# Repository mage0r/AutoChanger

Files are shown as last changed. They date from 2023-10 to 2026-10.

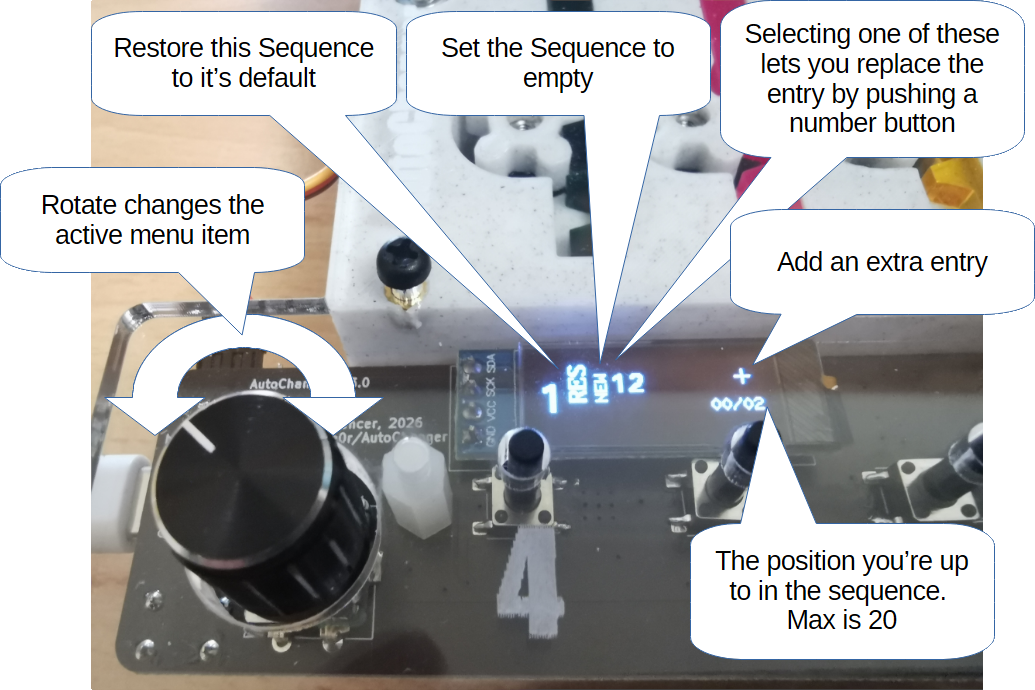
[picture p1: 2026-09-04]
images/Version3.9-howto-4.png

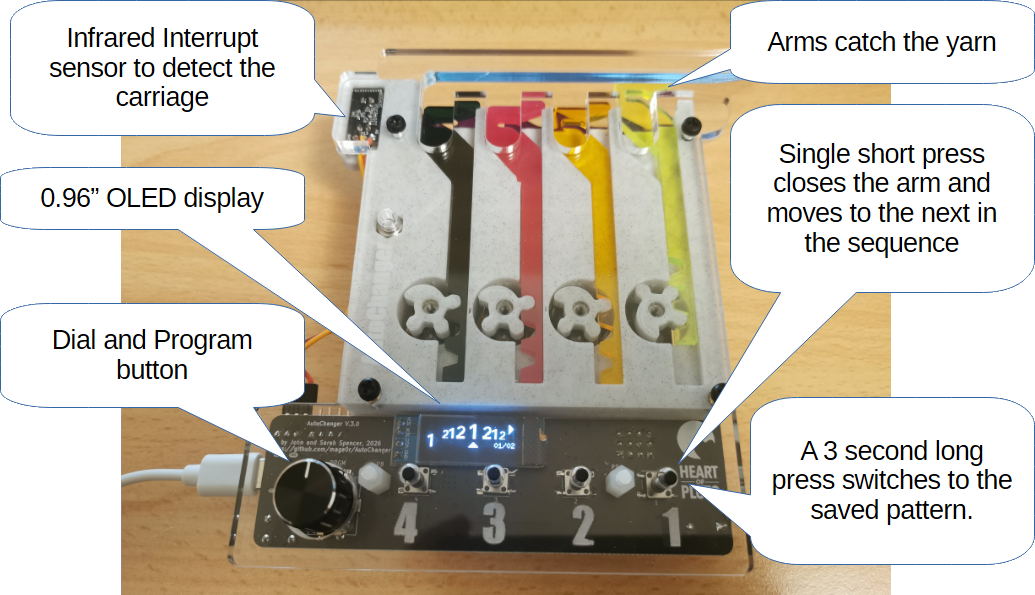
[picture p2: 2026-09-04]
images/Version3.9-howto-1.png

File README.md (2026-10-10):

AutoChanger - A Knitting Machine Auto Colour Changer to replace a Brother KRC-900
=============

This project was designed to provide a lower cost replacement for the commercial auto colour changer available from Brother for their 1980's electronic knitting machines.

How to use your AutoChanger
============

Thanks for purchasing or building your own AutoChanger.  I've put together a page of all the different features for you to try.

It is highly recommended you upgrade your AutoChanger firmware to the latest.  The current latest is v4.2.9

[How to Upgrade Your AutoChanger Firmware](https://github.com/mage0r/AutoChanger/wiki/How%E2%80%90to%E2%80%90upgrade)

[How to Use Your AutoChanger](https://github.com/mage0r/AutoChanger/wiki/How-to-use-Firmware-Version-4.2)

[Still using Version-3.9?  Check it out here](https://github.com/mage0r/AutoChanger/wiki/How-to-use-Firmware-Version-3.9)

Where did this come from?
============

You can read about the progress of this design at the following links:

[Building a better colour changer - Part 1 - Designing Hardware](https://github.com/mage0r/AutoChanger/wiki/Building-a-better-Colour-Changer-%E2%80%93-Part-1-%E2%80%93-Designing-hardware)

[Building a better colour changer - Part 2 - Firing the lasers](https://github.com/mage0r/AutoChanger/wiki/Building-a-better-Colour-Changer-%E2%80%93-Part-2-%E2%80%93-Firing-the-Lasers)

[Building a Better Colour Changer – Interlude – The KRC-1000E](https://github.com/mage0r/AutoChanger/wiki/Building-a-Better-Colour-Changer-%E2%80%93-Interlude-%E2%80%93-The-KRC%E2%80%901000E)

[Building a Better Colour Changer – Part 3 – Revising the design](https://github.com/mage0r/AutoChanger/wiki/Building-a-Better-Colour-Changer-%E2%80%93-Part-3-%E2%80%93-Revising-the-design)

For the sake of completeness, the early versions of this project are described at [Hardware Version 1.0 to 2.0]https://github.com/mage0r/AutoChanger/wiki/Hardware-Version-1.0-to-2.0)

Version 2.0 to 3.0 was TinyPico Based.  You can read about it at [Hardware Version 2.0 to 3.0](https://github.com/mage0r/AutoChanger/wiki/Hardware-Version-2.0-to-3.0)

Version 3.0 is a whole new build using an ESP32s3.  You can read about it at [Hardware Version 3.0](https://github.com/mage0r/AutoChanger/wiki/Hardware-Version-3.0)

CREDITS
------------

This project was designed in 2017 by John and Sarah Spencer
 - [John Spencer](https://github.com/mage0r)
 - [Sarah Spencer](https://github.com/chixor)

Check us out at [Heart Of Pluto](http://heartofpluto.co)

Made at hackmelbourne.org!

SPECIAL THANKS
------------

To the HackMelbourne (CCHS, http://hackmelbourne.org) community of Melbourne, Australia.

To all other open-source developers whose countless hours supported every other aspect of this design.

DISTRIBUTION
------------
The specific terms of distribution of this project are governed by the
license referenced below. Please contact the copyright owner if you wish to modify the board for distribution. Please utilize this design for personal or research projects. Please acknowledge all contributors.

LICENSE
-------
Licensed under the TAPR Open Hardware License (www.tapr.org/OHL).
The "license" sub-folder also contains a copy of this license in plain text format.

Copyright John Spencer, Sarah Spencer, 2017

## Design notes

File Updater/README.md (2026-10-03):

# AutoChanger Deployment Tool

A simple GUI tool for updating an AutoChanger unit's firmware over USB,
without touching anything saved on the device (patterns, config, etc).

This was largely written by Claude Sonnet 5.

## Why this is safe

This tool writes **only** to the two app slots, `app0` (flash offset `0x10000`) and
`app1` (`0x150000`) — the same regions a normal Arduino IDE upload or an OTA update
writes to. It never touches:

- the bootloader
- the partition table
- the OTA boot-selector (`otadata`)
- the SPIFFS filesystem (patterns, config, web files)

**Both slots get the same image, on purpose.** On a unit that has never used OTA
the bootloader always runs `app0`. Once OTA has been used, `otadata` may point at
`app1` instead, and the tool doesn't read `otadata` to find out which is active.
Writing both means the unit boots the new firmware either way. The trade-off: on
an OTA-enabled unit the inactive slot normally holds the *previous* firmware as a
fallback, and this overwrites it — so there's no falling back to the old version
after an update.

This is correct for any unit on the **"Default 4MB with spiffs (1.2MB APP/1.5MB
SPIFFS)"** partition scheme — which includes any v3.9 unit, since those were never
re-partitioned. The tool does **not** currently read the unit's partition table to
confirm that: it only refuses a firmware file that's too large for a slot. If a
unit's scheme is ever changed (e.g. to use more of a 16MB chip's flash), the fixed
offsets and size in `deploy_tool.py` (`APP0_OFFSET`, `APP1_OFFSET`,
`APP0_MAX_SIZE`) would be wrong for it, and the tool would write to the wrong
place without complaint.

## Using it

1. Get the firmware `.bin`: in Arduino IDE, **Sketch > Export Compiled
   Binary**. This drops a `.bin` file next to your sketch.
2. Open the AutoChanger Deployment Tool.
3. Browse to that `.bin` file.
4. Plug the AutoChanger in over USB, click Refresh if needed, and select its
   port.
5. Click **Update Device**.

The tool checks the firmware isn't larger than the app partition can hold
before doing anything, and shows esptool's live output in the Details pane
so you can see exactly what's happening.

## First-time flash (brand new / blank device)

A chip that's never been flashed has no bootloader or partition table, so a
normal update - which only writes the app itself - produces nothing bootable.
Tick "This is a first-time flash on a brand new/blank device" under section 1
and the tool also writes:

| File | Offset | Purpose |
|---|---|---|
| bootloader.bin | `0x0` | second-stage bootloader (ESP32-S3-specific address) |
| partitions.bin | `0x8000` | the partition table itself |
| *(built into the tool)* | `0xe000` | `boot_app0.bin` - selects the first boot slot |
| firmware.bin | `0x10000` / `0x150000` | same as a normal update |

`boot_app0.bin` isn't sketch-specific - it's one fixed file from the ESP32 core
install, embedded directly in the tool rather than something you need to find.

`bootloader.bin` and `partitions.bin` **are** sketch-specific. Arduino's Export
Compiled Binary produces them next to your `.bin`, named `<sketch>.ino.bootloader.bin`
and `<sketch>.ino.partitions.bin` - the tool looks for them there automatically
and fills the fields in if found, or Browse to them otherwise.

Only use this on a device that's genuinely never been flashed. On a device that's
already running AutoChanger it's unnecessary - a normal update is all that's
needed - though since the bootloader/partition table/app all sit before SPIFFS
on the flash, it wouldn't touch your patterns or config even if run by mistake,
as long as the partition scheme itself doesn't change.

## Clearing files after an update (optional)

Ticking files under "3. Clear files on update" makes the tool, once the unit has
restarted on the new firmware, delete them over serial (`RM`) and then run `FIX`
so the unit recreates fresh defaults. The firmware only writes its default web
pages at startup when `config.ini` is missing, so `FIX` is what actually brings
the pages back straight away.

- **HTML & SVG** (ticked by default) and **Patterns** are recreated immediately.
- **Config** is removed *last*, after `FIX`. `FIX` rebuilds `config.ini` from what
  the unit currently has in memory, so removing it first would just write your
  old settings back. It resets to defaults the next time the unit restarts.
- This needs firmware with the serial command feature (`RM`/`FIX`, v4.1+). On
  anything older the tool logs "no response" for each step and carries on.

## Update logs

After every update attempt - successful or not - the tool saves the contents of
the Details pane to a timestamped file such as
`AutoChanger-deploy-2026-09-28_14-30-05.log`, and shows the path when it
finishes. It's written next to the tool (falling back to your home folder, then
the temp folder, if that location isn't writable). Each log starts with a
header - result, port, firmware file with its size and SHA-256, which files were
cleared, and OS/Python/esptool versions - followed by every line of output with a time. Handy to attach when
something goes wrong. Each log only contains what happened since the previous
one, so logs from several updates in one session don't repeat each other.

## Building the executable yourself

PyInstaller can't cross-compile — a Windows `.exe` has to be built on
Windows, a Mac app on a Mac. This folder includes:

- `deploy_tool.py` — the actual tool (pure Python, runs anywhere Python 3 +
  the two requirements are installed, no build needed for that).
- `requirements.txt` — `esptool` and `pyserial`.
- `build_windows.bat` — run on a Windows machine to produce
  `dist\AutoChangerDeployTool.exe`.
- `build_unix.sh` — run on Mac or Linux to produce
  `dist/AutoChangerDeployTool` (Mac users get an unsigned binary; first
  launch may need a right-click > Open to bypass Gatekeeper once).

A Linux build was already produced and tested as part of building this tool
(the build completed cleanly with all dependencies resolving, and the
resulting binary launches and initializes without error) — running the
matching script on Windows and Mac will produce the equivalents for those
platforms.

## Known limitation

Right now this only performs the **safe, app-only update**. It does not yet
support the (destructive) full repartition-and-reflash path for moving a
unit onto a larger partition scheme to use more of a 16MB chip's flash —
that needs a SPIFFS backup/restore step built in before it's safe to offer,
and is intentionally left out of this first version.

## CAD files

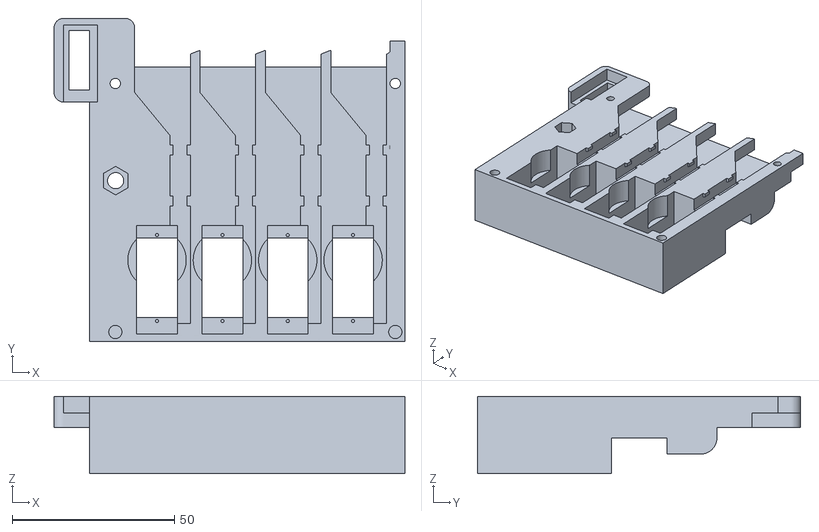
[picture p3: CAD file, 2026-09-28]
Hardware/changer.v.3.0.frame.stl
108.2 x 99.7 x 23.8

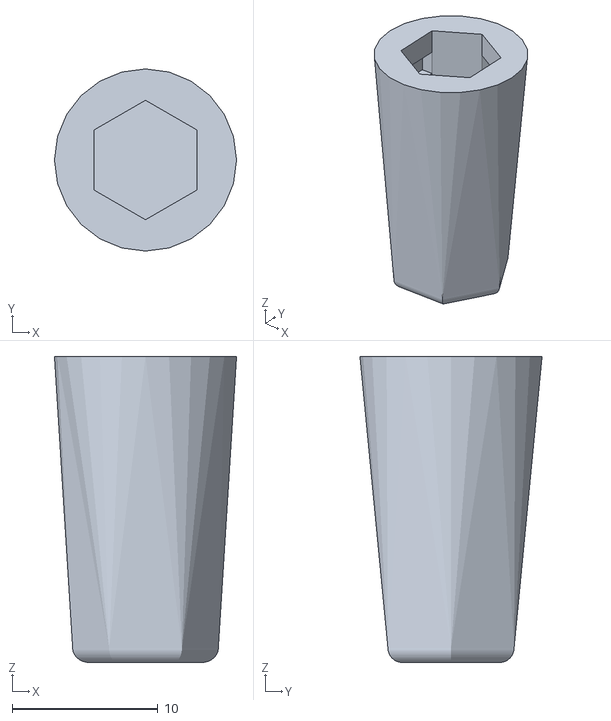
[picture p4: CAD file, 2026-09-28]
Hardware/changer.v.3.0.nut.stl
12.5 x 12.5 x 21.0

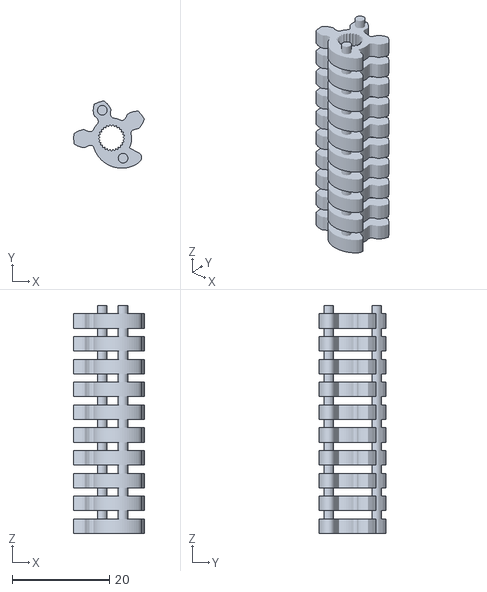
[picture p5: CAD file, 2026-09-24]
Hardware/changer.v.3.0.gearx10.stl
14.6 x 13.9 x 47.0

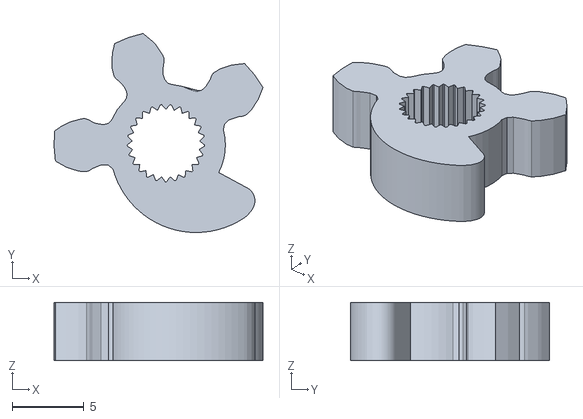
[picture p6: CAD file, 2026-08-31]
Hardware/changer.v.3.0.gear.stl
14.6 x 13.9 x 4.05

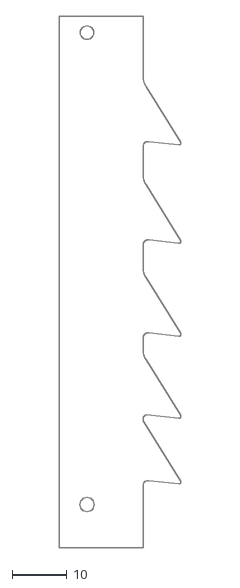
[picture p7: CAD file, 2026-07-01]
Hardware/changer.v.3.0.comb.dxf
22.2 x 97.2

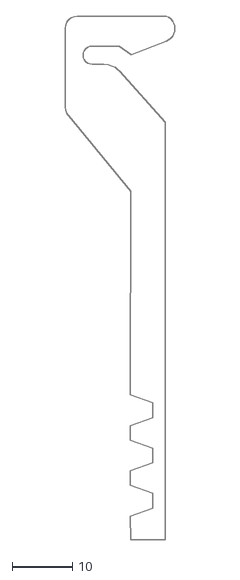
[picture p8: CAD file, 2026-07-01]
Hardware/changer.v.3.0.arm.dxf
18.2 x 87.1

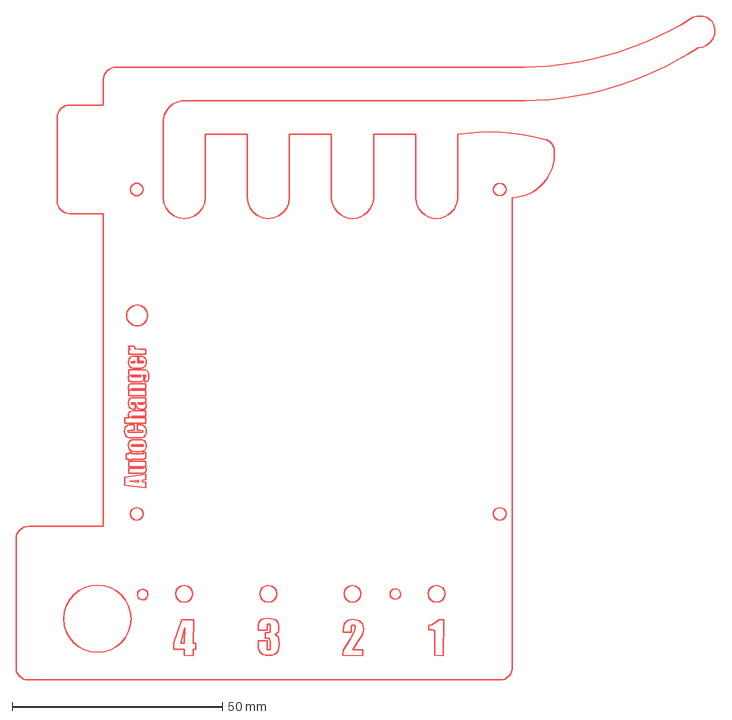
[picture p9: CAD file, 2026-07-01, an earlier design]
Hardware/changer.v.2.5.top.dxf
166.4 x 157.9 mm

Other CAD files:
Hardware/changer.v.3.0.top.dxf
Hardware/changer.v.3.0.skp

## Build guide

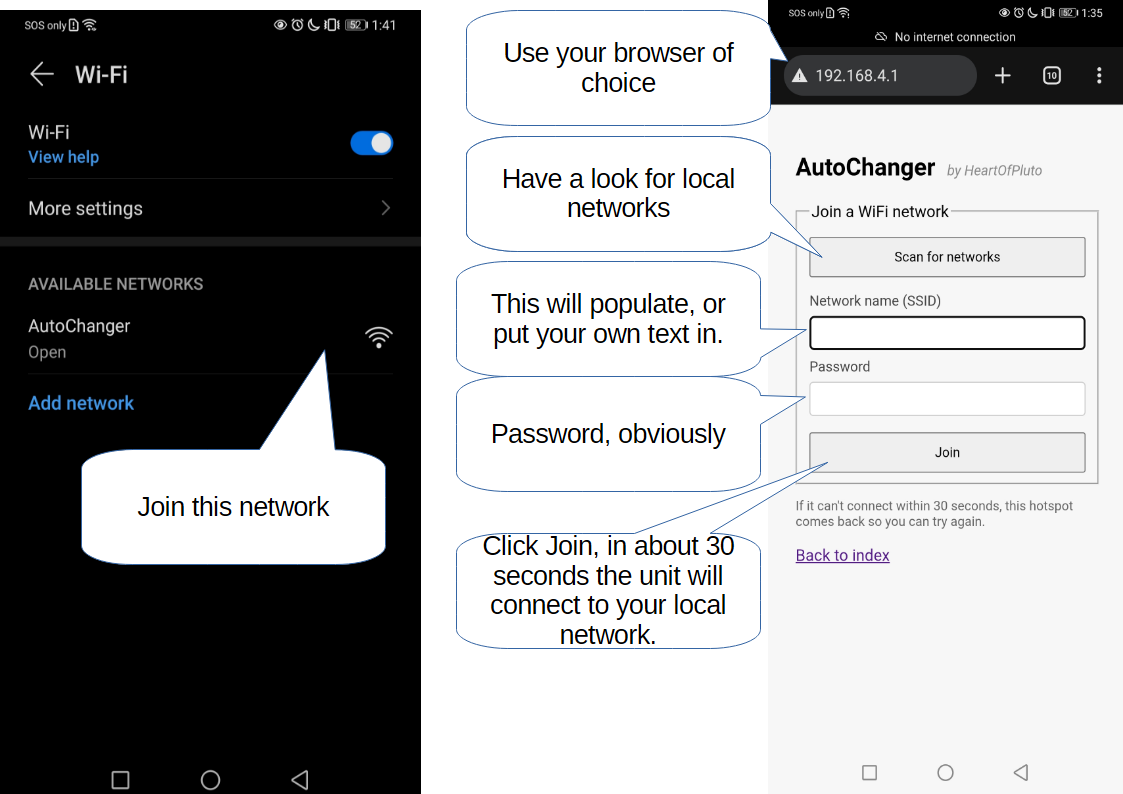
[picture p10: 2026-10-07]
images/Version4.2-howto-7.png

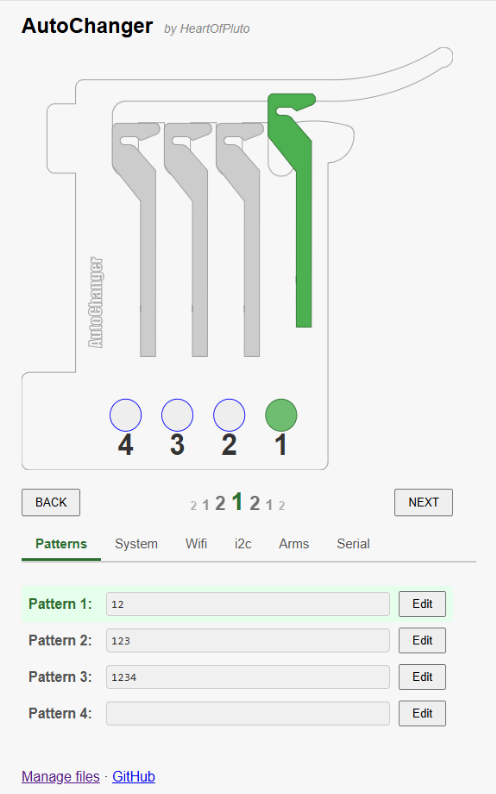
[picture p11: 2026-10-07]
images/Version4.2-howto-8.png

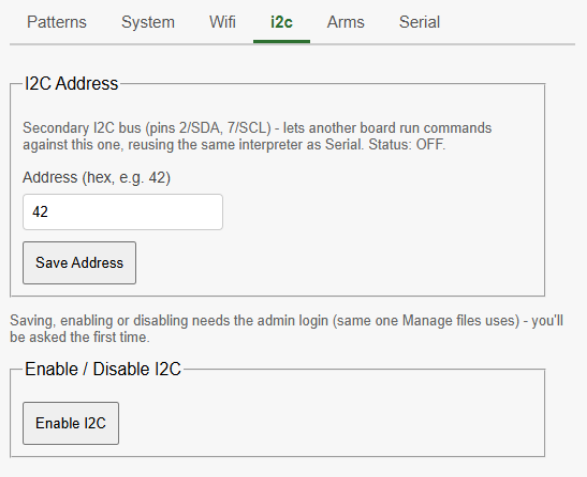
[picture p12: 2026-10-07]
images/Version4.2-howto-11.png

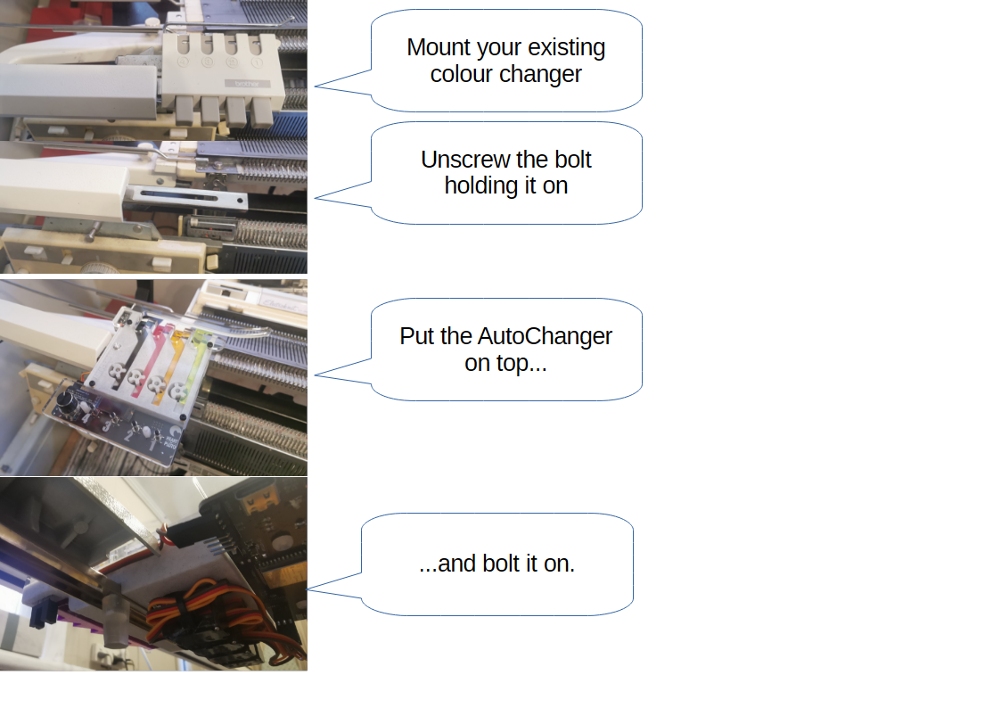
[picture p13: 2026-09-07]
images/Version3.9-howto-5.png

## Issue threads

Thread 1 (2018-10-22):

STEP/dwg files

wifasoi, 2018-10-22:
Hi,
I know i can install sketchup and export from there the necessary files, but i'm a linux user and installing sketchup and use it with wine is a pain (I tried and doesn't work, unfortunately). -*github whiny/entitled user mode engaged*- Can you export the project in for an export of the files in a STEP format (preferred, otherwise stl is workable too), or in this case DWG/dxf/svg would be fine too (but i think there is more work involved). If you don't want to track those files, you can put in a github release (so you don't have to worry about out of sync files).

This is because I want to create a version that work with the ayab board (shhh, is a secret... the ayab peaple dosn't know about it... yet :P) and use a sx1508/9 (I2C IO expander with pwm).

You can close this issue if you don't have time to do it or you think I was too rude... I don't mind.
Thank you for your consideration.

wifasoi, 2018-10-22:
-*event more entiteld github user mode engaged*-
the license requires it   https://github.com/mage0r/AutoChanger/blob/9e84eed463dcbbb184bd24fda50bc8b92860e9d6/Hardware/TAPR_Open_Hardware_License_v1.0.txt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

mage0r, 2018-10-22:
Ah, also, there is a serial/software i2c 4 pin port broken out on the circuit board design that was always intended to provide an uplink to a controller.

You are of course clear to solve the problem any way you like, but having an independent controller provides a few extra advantages.   For example, the user can move threads or change order in the event of a failure.

I've been tempted to do some work with the AYAB project a few times but have been a bit time limited and focused on approaches that are controller agnostic.

wifasoi, 2018-10-23:
I choose the Semtex because you can read key and command LEDs.. but unfortunately I can control servo (learned the hard way)... (I'll use a combination of mpc23017 and some low cost io expander).
And leave the ayab controller do the dirty work... So I don't have to program another micro.
Another reason is to minimize the cost of (ipotetical) product (don't want to transform in a real product, I like to challenge myself :D).

And for the sake of argument:
In theory you can change license whenever you want.. so the rule do not apply to the copyright holder. You are right (if you are the only copyright holder)

And for the sake of argument, again,
maibe DWG is not the best example, but the other are so main stream that are considered "exchange format" between cad programs (STL is the JPEG of the 3d models... I despise them as a exchange format). In the license there are example of "Gerber" and "pdf", once proprietary now so whidespread that are considered "exchange format".

And for last: you can make a GitHub release anytime you want(don't think you need to tag your repo), and you can add out-of-tree files (they are not added to the repo), so it's perfect for adding binary files specific to a commit (or in this case, cad export).

And thanks for your consideration.

wifasoi, 2018-10-23:
Wow, that was log...
TL;DR: you're right. I meant any cad exchange file. GitHub release are perfect to add out-of-tree files. And thanks for your time.

mage0r, 2018-10-23:
https://github.com/mage0r/AutoChanger/releases/tag/1.6

Closed 2018-10-23.

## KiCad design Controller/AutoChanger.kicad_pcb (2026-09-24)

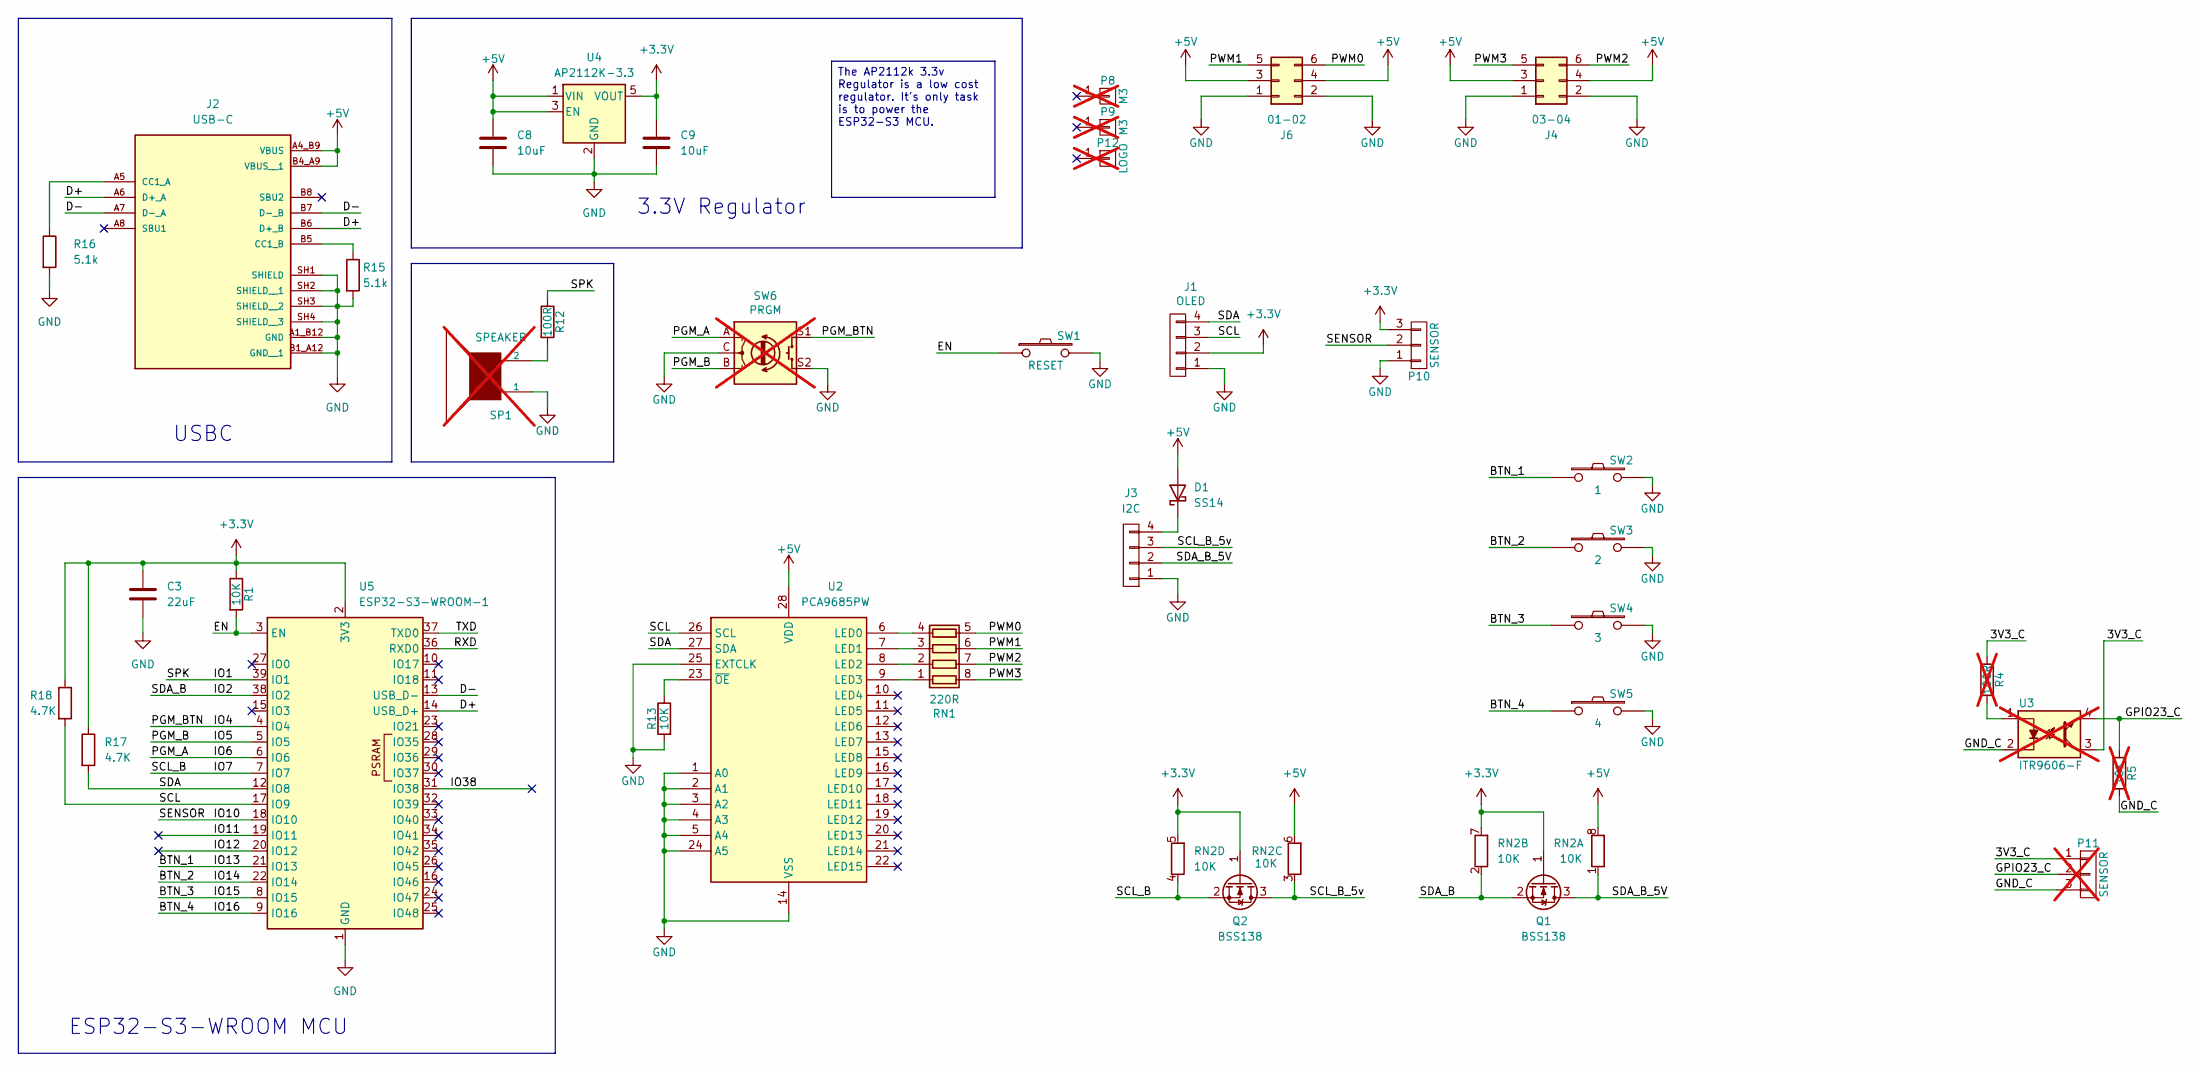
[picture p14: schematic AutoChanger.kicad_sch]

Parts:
C3: 22uF; C_0603_1608Metric; LCSC C59461
C8, C9: 10uF; C_0603_1608Metric; LCSC C19702
D1: SS14; D_SMA; LCSC C2480
J1: OLED; 0.91 OLED; LCSC C5248081
J2: USB-C; AMPHENOL_12402012E212A; PARTREV 4; LCSC C5150972
J3: I2C; CONN-SMD_PH2.0MM-4P-WT; LCSC C53055420
J4: 03-04; HDR-SMD_6P-P2.54-V-M-R2-C3-LS7.5-2; LCSC C3294461
J6: 01-02; HDR-SMD_6P-P2.54-V-M-R2-C3-LS7.5-2; LCSC C3294461
P8, P9: M3; MountingHole_3.2mm_M3; not fitted
P10: SENSOR; CONN-SMD_PH2.0MM-3P-WT; LCSC C53055419
P11: SENSOR; PinHeader_1x03_P2.54mm_Vertical; not fitted
P12: LOGO; logo; not fitted
Q1, Q2: BSS138; SOT-23; LCSC C8490
R1, R13: 10K; R_0603_1608Metric_Pad0.98x0.95mm_HandSolder; LCSC C25804
R4: 100R; R_0603_1608Metric_Pad0.98x0.95mm_HandSolder; LCSC C22775; not fitted
R5: 10K; R_0603_1608Metric_Pad0.98x0.95mm_HandSolder; LCSC C25804; not fitted
R12: 100R; R_0603_1608Metric_Pad0.98x0.95mm_HandSolder; LCSC C22775
R15, R16: 5.1k; R_0603_1608Metric_Pad0.98x0.95mm_HandSolder; LCSC C23186
R17, R18: 4.7K; R_0603_1608Metric_Pad0.98x0.95mm_HandSolder; LCSC C23162
RN1: 220R; R_Array_Concave_4x0603; LCSC C29719
RN2: 10K; R_Array_Convex_4x0603; LCSC C29718
SP1: SPEAKER; Buzzer_12x9.5RM7.6; not fitted
SW1: RESET; SW_SPST_PTS645Sx43SMTR92; LCSC C557614
SW2: 1; SW_SPST_PTS645Sx43SMTR92; LCSC C53202676
SW3: 2; SW_SPST_PTS645Sx43SMTR92; LCSC C53202676
SW4: 3; SW_SPST_PTS645Sx43SMTR92; LCSC C53202676
SW5: 4; SW_SPST_PTS645Sx43SMTR92; LCSC C53202676
SW6: PRGM; RotaryEncoder_Alps_EC12E-Switch_Vertical_H20mm; LCSC C470742; not fitted
U2: PCA9685PW; TSSOP-28_4.4x9.7mm_P0.65mm; LCSC C2678753
U3: ITR9606-F; ITR9606; not fitted
U4: AP2112K-3.3; SOT-23-5; LCSC C51118
U5: ESP32-S3-WROOM-1; LCSC C2913202

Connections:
+3.3V: C3.1, C9.1, J1.2, P10.3, Q1.1 (G), Q2.1 (G), R1.1, R17.1, R18.1, RN2.5 (R4.2), RN2.7 (R2.2), U4.5 (VOUT), U5.2 (3V3)
+5V: C8.1, D1.2 (A), J2.A4_B9 (VBUS), J2.B4_A9 (VBUS__1), J4.3, J4.4, J6.3, J6.4, RN2.6 (R3.2), RN2.8 (R1.2), U2.28 (VDD), U4.1 (VIN), U4.3 (EN)
/3V3_C: P11.1, R4.1, U3.3
/BTN_1: SW2.1, U5.21 (IO13)
/BTN_2: SW3.1, U5.22 (IO14)
/BTN_3: SW4.1, U5.8 (IO15)
/BTN_4: SW5.1, U5.9 (IO16)
/D+: J2.A6 (D+_A), J2.B6 (D+_B), U5.14 (USB_D+)
/D-: J2.A7 (D-_A), J2.B7 (D-_B), U5.13 (USB_D-)
/EN: R1.2, SW1.1, U5.3 (EN)
/GND_C: P11.3, R5.2, U3.2
/GPIO23_C: P11.2, R5.1, U3.4
/IO1: R12.1, U5.39 (IO1)
/IO2: Q1.2 (S), RN2.2 (R2.1), U5.38 (IO2)
/IO4: SW6.S1, U5.4 (IO4)
/IO5: SW6.B, U5.5 (IO5)
/IO6: SW6.A, U5.6 (IO6)
/IO7: Q2.2 (S), RN2.4 (R4.1), U5.7 (IO7)
/IO10: P10.2, U5.18 (IO10)
/IO11: U5.19 (IO11)
/IO12: U5.20 (IO12)
/IO38: U5.31 (IO38)
/PWM0: J6.6, RN1.5 (R4.2)
/PWM1: J6.5, RN1.6 (R3.2)
/PWM2: J4.6, RN1.7 (R2.2)
/PWM3: J4.5, RN1.8 (R1.2)
/RXD: U5.36 (RXD0)
/SCL: J1.3, R18.2, U2.26 (SCL), U5.17 (IO9)
/SCL_B_5v: J3.3, Q2.3 (D), RN2.3 (R3.1)
/SDA: J1.4, R17.2, U2.27 (SDA), U5.12 (IO8)
/SDA_B_5V: J3.2, Q1.3 (D), RN2.1 (R1.1)
/TXD: U5.37 (TXD0)
GND: C3.2, C8.2, C9.2, J1.1, J2.A1_B12 (GND), J2.B1_A12 (GND__1), J2.SH1 (SHIELD), J2.SH2 (SHIELD__1), J2.SH3 (SHIELD__2), J2.SH4 (SHIELD__3), J3.1, J4.1, J4.2, J6.1, J6.2, P10.1, R13.2, R15.2, R16.2, SP1.1, SW1.2, SW2.2, SW3.2, SW4.2, SW5.2, SW6.C, SW6.S2, U2.1 (A0), U2.2 (A1), U2.3 (A2), U2.4 (A3), U2.5 (A4), U2.14 (VSS), U2.24 (A5), U2.25 (EXTCLK), U4.2 (GND), U5.1 (GND), U5.40 (GND), U5.41 (GND)
unnamed: D1.1 (K), J3.4
unnamed: J2.A5 (CC1_A), R16.1
unnamed: J2.B5 (CC1_B), R15.1
unnamed: R4.2, U3.1
unnamed: R12.2, SP1.2
unnamed: RN1.1 (R1.1), U2.9 (LED3)
unnamed: RN1.2 (R2.1), U2.8 (LED2)
unnamed: RN1.3 (R3.1), U2.7 (LED1)
unnamed: RN1.4 (R4.1), U2.6 (LED0)
unnamed: R13.1, U2.23 (~OE)

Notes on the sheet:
USBC
ESP32-S3-WROOM MCU
3.3V Regulator
The AP2112k 3.3v Regulator is a low cost regulator. It's only task is to power the ESP32-S3 MCU.

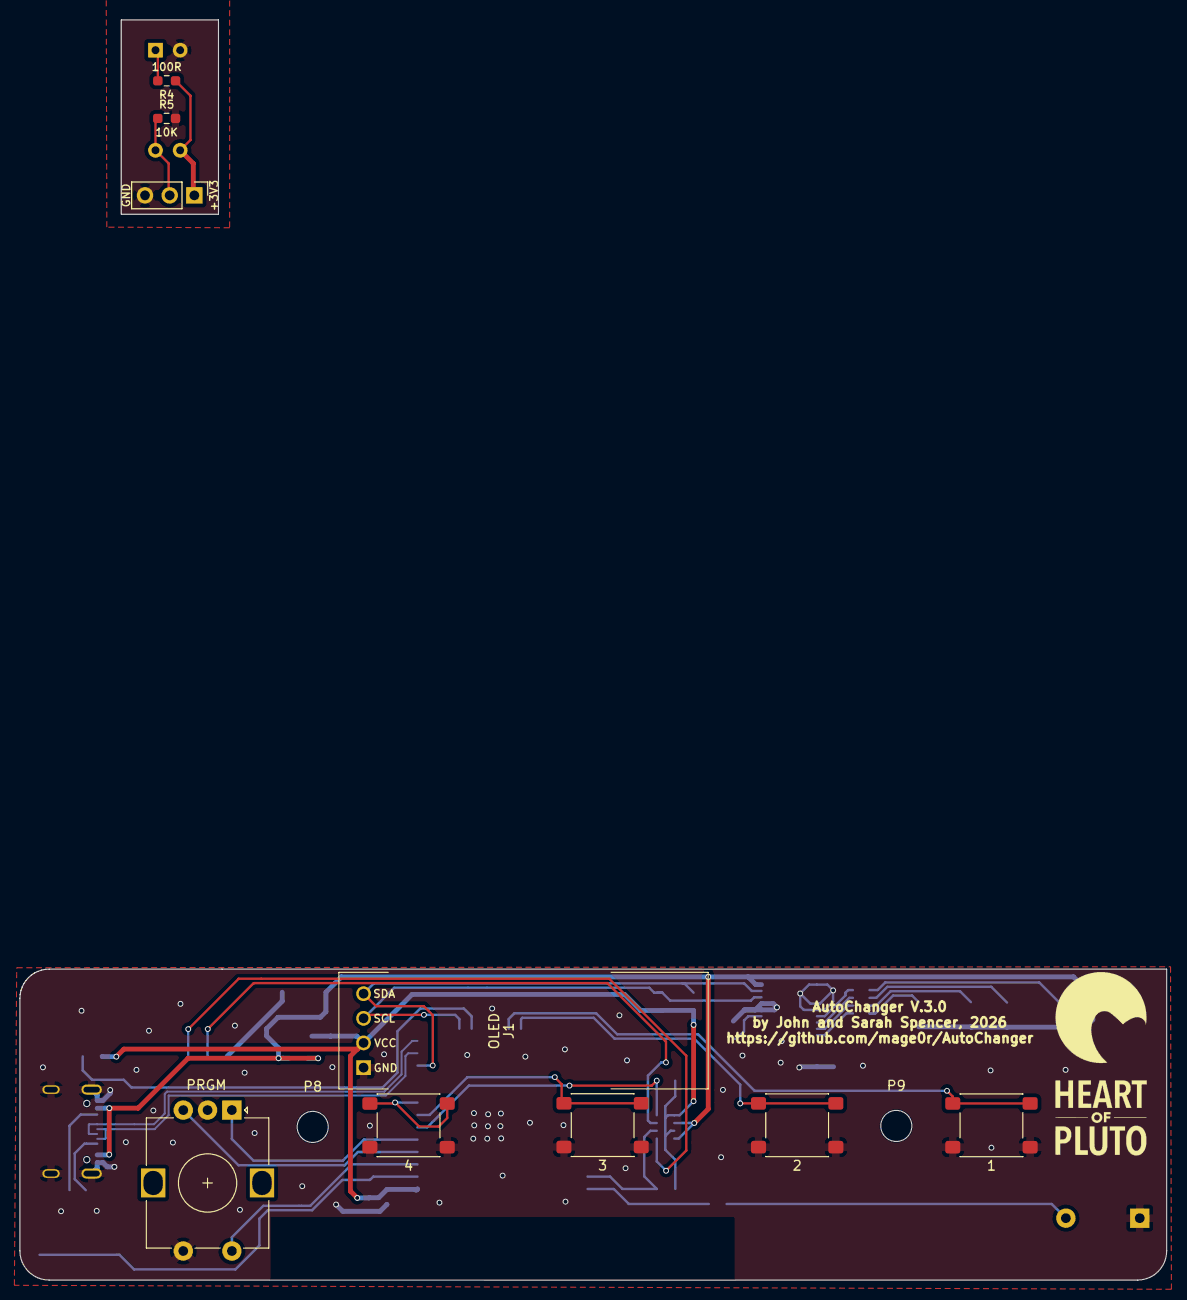
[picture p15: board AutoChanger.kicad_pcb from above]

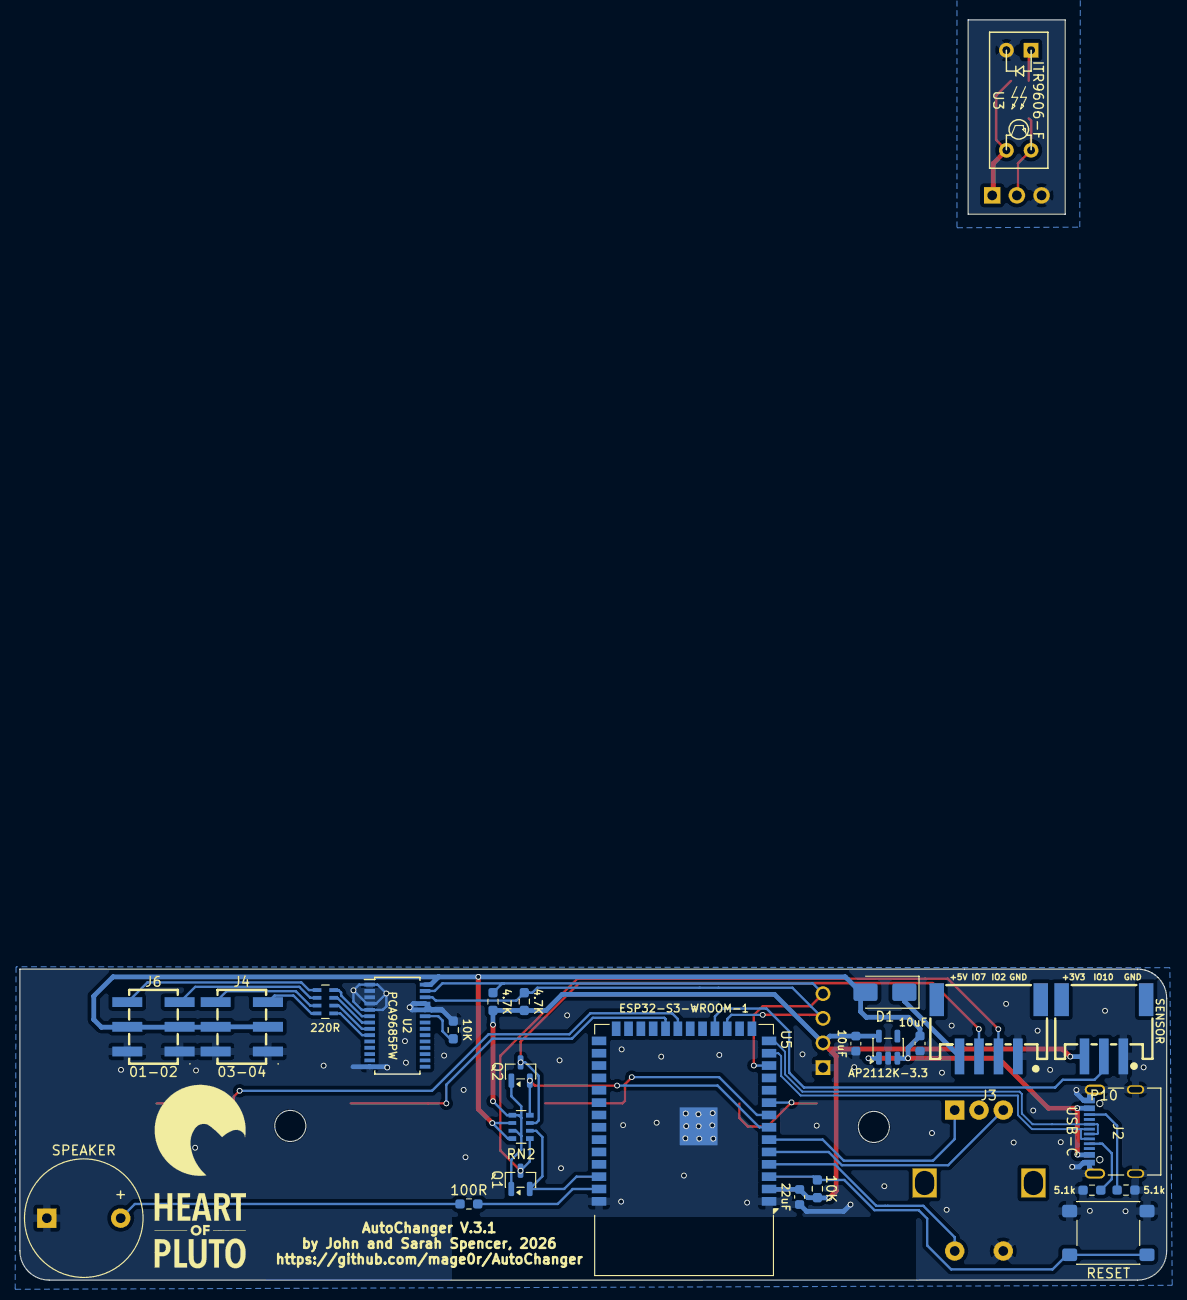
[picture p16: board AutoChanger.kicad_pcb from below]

Board: 2 copper layers, 118.0 x 32.0 mm, 39 parts (27 on the bottom side), 38 nets.

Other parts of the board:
P12#2: LOGO; logo

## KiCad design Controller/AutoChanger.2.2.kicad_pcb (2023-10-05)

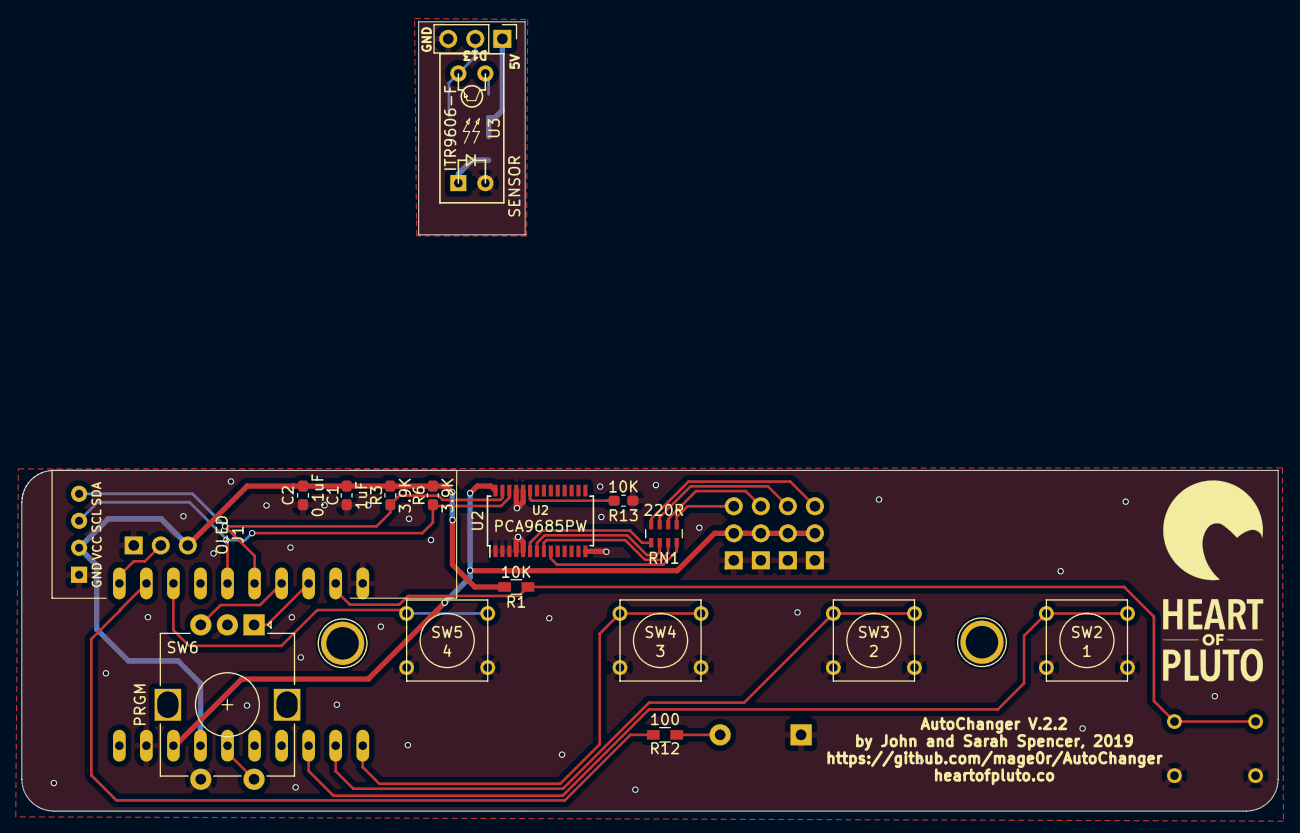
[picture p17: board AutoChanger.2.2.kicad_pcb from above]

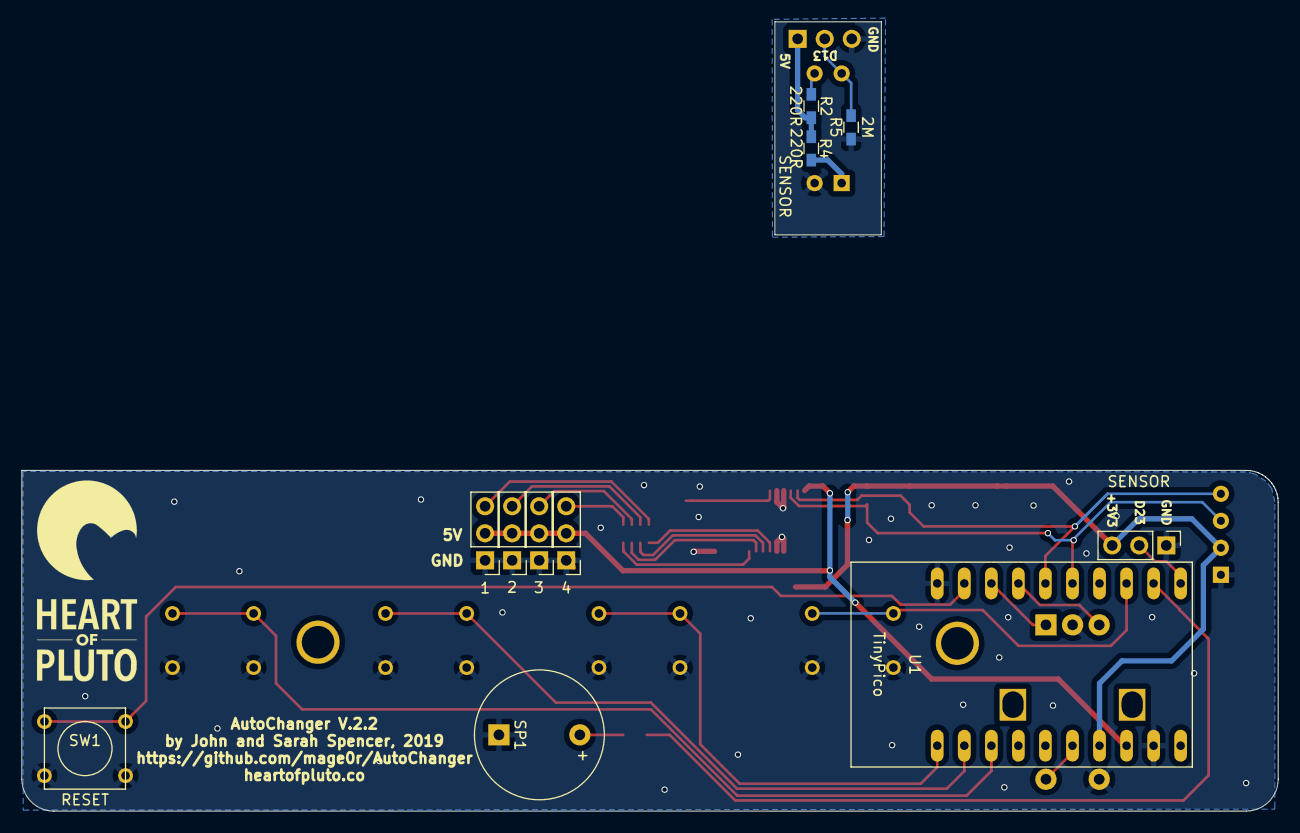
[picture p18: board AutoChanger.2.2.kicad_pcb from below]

Board: 2 copper layers, 118.0 x 32.0 mm, 32 parts (12 on the bottom side), 30 nets.

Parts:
C1: 1uF; C_0603_1608Metric_Pad1.05x0.95mm_HandSolder
C2: 0.1uF; C_0603_1608Metric_Pad1.05x0.95mm_HandSolder
J1: OLED; 0.91 OLED
P3: 1; Pin_Header_Straight_1x03_Pitch2.54mm
P4: 2; Pin_Header_Straight_1x03_Pitch2.54mm
P5: 3; Pin_Header_Straight_1x03_Pitch2.54mm
P6: 4; Pin_Header_Straight_1x03_Pitch2.54mm
P8, P9: M3; 1pin
P10, P11: SENSOR; Pin_Header_Straight_1x03_Pitch2.54mm
P12, P12#2: LOGO; logo
R1: 10K; R_0603_HandSoldering
R2, R4: 220R; R_0603_HandSoldering
R3, R6: 3.9K; R_0603_1608Metric_Pad1.05x0.95mm_HandSolder
R5: 2M; R_0603_HandSoldering
R12: 100; R_0603_HandSoldering
R13: 10K; R_0603_1608Metric_Pad1.05x0.95mm_HandSolder
RN1: 220R; R_Array_Concave_4x0603
SP1: SPEAKER; Buzzer_12x9.5RM7.6
SW1: RESET; SW_PUSH_SMALL
SW2: 1; SW_PUSH_SMALL
SW3: 2; SW_PUSH_SMALL
SW4: 3; SW_PUSH_SMALL
SW5: 4; SW_PUSH_SMALL
SW6: PRGM; RotaryEncoder_Alps_EC12E-Switch_Vertical_H20mm
U1: TinyPico
U2: PCA9685PW; TSSOP-28_4.4x9.7mm_P0.65mm
U3: ITR9606-F; ITR9606

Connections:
+3V3: C1.1, C2.1, J1.2, P10.3, R1.1, R3.1, R6.1, U1.7
+5V: P3.2, P4.2, P5.2, P6.2, U1.8, U2.28
/3V3_C: P11.1, R2.1, R4.1
/GND_C: P11.3, R5.2, U3.2
/GPIO4: SW6.S1, U1.6
/GPIO18: SW5.1, U1.13
/GPIO19: R12.1, U1.12
/GPIO23: P10.2, U1.11
/GPIO25: SW4.1, U1.1
/GPIO25_C: P11.2, R5.1, U3.4
/GPIO26: SW3.1, U1.2
/GPIO27: SW2.1, U1.3
/GPIO32: SW6.B, U1.17
/GPIO33: SW6.A, U1.18
/PWM0: P3.3, RN1.8
/PWM1: P4.3, RN1.7
/PWM2: P5.3, RN1.6
/PWM3: P6.3, RN1.5
/RESET: R1.2, SW1.1, U1.19
/SCL: J1.3, R6.2, U1.15, U2.26
/SDA: J1.4, R3.2, U1.16, U2.27
GND: C1.2, C2.2, J1.1, P3.1, P4.1, P5.1, P6.1, P10.1, R13.2, SP1.1, SW1.2, SW2.2, SW3.2, SW4.2, SW5.2, SW6.C, SW6.S2, U1.9, U1.20, U2.1, U2.2, U2.3, U2.4, U2.5, U2.14, U2.24, U2.25
unnamed: R2.2, U3.3
unnamed: R4.2, U3.1
unnamed: R12.2, SP1.2
unnamed: R13.1, U2.23
unnamed: RN1.1, U2.6
unnamed: RN1.2, U2.7
unnamed: RN1.3, U2.8
unnamed: RN1.4, U2.9

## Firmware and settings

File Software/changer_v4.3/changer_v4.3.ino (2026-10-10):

/*************************************************** 
 *  
 *  
 *  Autochanger - https://github.com/mage0r/AutoChanger
 *  
 *  Nano's are out, TinyPICO's are out, ESP32-S3 WROOM modules are in.
 *  
 *  Probably worth some justification there.  There weren't enough clock cycles to update the screen AND make
 *  sure I didn't miss any event triggers from the sensor.  Generally, the Nano only having two interrupt pins
 *  didn't help.
 *
 * The TinyPICO's are a bit pricey and getting hard to get.
 *  
 *  Oh god, please don't keep reading this code.  It is awful.  It was awful before and Claude has been contributing.
 *  
 *
 ****************************************************/

// Set our version number.  Don't forget to update when featureset changes
#define PROJECT "AutoChanger"
#define VERSION "V.4.3.2"

#include <Wire.h>
#include <Bounce2.h>
#include <Adafruit_PWMServoDriver.h>

// webserver contains all the variables and the like
// needed to run the ESP32 manager.
#include "webserver.h"

// patterns.h contains all the types and globals for pattern storage.
#include "patterns.h"

// arm.h contains the arm-sensor debounce/pass-counter globals.
#include "arm.h"

// button.h contains the button-debounce state globals.
#include "button.h"

// A fixed-size ring buffer that tees everything written to it out to the real
// Serial (so the USB monitor keeps working exactly as before) and also keeps the
// most recent bytes in RAM, so the web UI's Serial Log tab can show them too. This
// is the main sketch file specifically so every other file can see the global
// instance below - per Arduino's own build docs, this file (matching the sketch
// folder's name) is always concatenated first, so a global declared here is the
// only kind guaranteed visible everywhere else, regardless of those other files'
// alphabetical order.
#define LOG_BUFFER_SIZE 4096

byte DEBUG = 0; // 0 = off, 1 = normal (if(DEBUG) throughout this codebase - fires for
                 // any non-zero value, including 2), 2 = also prefixes every line
                 // weblog prints with a millis() timestamp (see LogBuffer::write()
                 // just below) - for digging into timing-sensitive issues, where
                 // WHEN each of the existing log lines happened matters, not just
                 // their order. Nothing has to be added anywhere to use this - every
                 // weblog.print()/println() call already in the codebase gets
                 // timestamped automatically once this is 2.

class LogBuffer : public Print {
  public:
    size_t write(uint8_t c) override {
      // Stamps the START of each line, not every byte - checked here so it applies
      // to every existing call site for free, rather than needing every single
      // weblog.print() throughout the codebase to be changed individually.
      if(DEBUG >= 2 && atLineStart) {
        String prefix = String(millis()) + ": ";
        for(size_t i = 0; i < prefix.length(); i++)
          writeRaw((uint8_t)prefix[i]);
        atLineStart = false;
      }
      writeRaw(c);
      if(c == '\n')
        atLineStart = true;
      return 1;
    }
    size_t write(const uint8_t *data, size_t size) override {
      for(size_t i = 0; i < size; i++)
        write(data[i]);
      return size;
    }
    // Oldest-to-newest, exactly as Serial would have shown it.
    String getContents() {
      String result;
      result.reserve(filled);
      size_t start = (filled < LOG_BUFFER_SIZE) ? 0 : head;
      for(size_t i = 0; i < filled; i++) {
        result += (char)buf[(start + i) % LOG_BUFFER_SIZE];
      }
      return result;
    }
    void clear() {
      head = 0;
      filled = 0;
    }
  private:
    void writeRaw(uint8_t c) {
      Serial.write(c);
      buf[head] = c;
      head = (head + 1) % LOG_BUFFER_SIZE;
      if(filled < LOG_BUFFER_SIZE)
        filled++;
    }
    uint8_t buf[LOG_BUFFER_SIZE];
    size_t head = 0;
    size_t filled = 0;
    bool atLineStart = true;
};

LogBuffer weblog;
// 2 shows timing information.
boolean BUZZER = 1; // Is the buzzer on or off. used to be a define, now a bool.

#define ARM 10
#define BUTTON_1 13
#define BUTTON_2 14
#define BUTTON_3 15
#define BUTTON_4 16
#define PGRM_BTN 4
#define PGRM_A 6
#define PGRM_B 5
#define BUZZER_PIN 1

// Secondary I2C bus (see i2c.ino) - this device acts as the I2C peripheral, reusing
// the same command interpreter as Serial.
#define I2C2_SDA 2
#define I2C2_SCL 7
#define I2C2_ADDRESS_DEFAULT 0x42 // used if i2c2_address in config.ini is missing or out of range
#define I2C2_RESPONSE_MAX 120 // stay comfortably under the ~126 usable bytes of Wire's 128-byte buffer

boolean i2c_enabled = false; // persisted in config.ini - see I2C_ENABLE in commands.ino
boolean sensor_enabled = true; // persisted in config.ini - see SENSOR_ENABLE in commands.ino
uint8_t i2c2_address = I2C2_ADDRESS_DEFAULT; // persisted in config.ini - 7-bit address, 0x08-0x77


// The colour changer only uses 4 servos.
// content for this array is loaded from eeprom
// closed, open, eject
int servos[4][3];

unsigned long servoTimeout = 0;

unsigned long debugUpdate = 0;

// our servo # counter
int servonum = 1;
uint8_t maxServo = 4;

Adafruit_PWMServoDriver pwm = Adafruit_PWMServoDriver();

// We track how many movements the servo has made.
// because, why not?! :)
unsigned int servoCount[4];
unsigned int oldservoCount[4];
unsigned long countSaveMillis;
unsigned int countSaveTime = 300000; // 5 minutes

// Rotary encoder
long oldPosition  = 0; // matches encoder.setCount(0) in setup_encoder()
byte menu_page = 0;
int menu_position = 0;
byte admin_mode = 0;
int temp_menu_position = 0;


// Buzzer
double buzzerNote = 1046.502;

unsigned int test_run = 10;

// Non-blocking tones
unsigned long tone_start = 0;
unsigned long tone_len = 0;
bool tone_active = false;

// Display update limiter
unsigned int displayUpdateTimer = 100;
unsigned long displayUpdate = 0;

// function prototypes.
// annoyingly, not evertything needs these.
void IRAM_ATTR arm_sensor_handler();

//time logging.
unsigned long timeLogging[2][11] = {{0,0,0,0,0,0,0,0,0,0,0},
                                    {0,0,0,0,0,0,0,0,0,0,0}};

// This is used by my runEvery Function.
// The name is arbitrary and you should create
// a new variable for each timed instance.
unsigned long run1000 = 0;
unsigned long run400 = 0;

void setup() {
  Serial.begin(115200);

  // First, build information
  weblog.print(F(PROJECT));
  weblog.print(F(" "));
  weblog.println(F(VERSION));
  weblog.print(F("Build Date: "));
  weblog.println(F(__DATE__ " " __TIME__));
  weblog.print(F("Free Ram: "));
  weblog.print(ESP.getFreeHeap() / 1024);
  weblog.println(F(" KB"));

  // Chip/flash identity - compare "Flash Size" against whatever the Arduino IDE's
  // Tools > Flash Size is set to. A mismatch there (not in this code) is the usual
  // cause of a wrong/too-small LittleFS partition.
  weblog.print(F("Chip Model: "));
  weblog.print(ESP.getChipModel());
  weblog.print(F(" rev"));
  weblog.println(ESP.getChipRevision());
  weblog.print(F("Flash Size: "));
  weblog.print(ESP.getFlashChipSize() / 1024 / 1024);
  weblog.println(F(" MB"));
  weblog.print(F("Sketch Size: "));
  weblog.print(ESP.getSketchSize() / 1024);
  weblog.print(F(" KB, Free Sketch Space: "));
  weblog.print(ESP.getFreeSketchSpace() / 1024);
  weblog.println(F(" KB"));

  setup_config();

  // I can't explain this, but if the display is set up after the servos it all falls apart
  setup_display();

  // mounts LittleFS, carrying files across from a pre-4.3 LittleFS filesystem if
  // that's what's on the partition - see filesystem.ino
  if(!mount_filesystem()) {
    weblog.println(F("Filesystem mount failed!"));
    return;
  } else {
    weblog.print(F("LittleFS Total: "));
    weblog.print(LittleFS.totalBytes() / 1024);
    weblog.print(F(" KB, Used: "));
    weblog.print(LittleFS.usedBytes() / 1024);
    weblog.println(F(" KB"));
    load_config(LittleFS, "/config.ini");
    create_missing_pages();
    log_page_status();
  }

  // set up the Interrupts
  setup_interrupts();

  // Encoder config.
  setup_encoder();

  // buzzer config
  setup_buzzer();

  setup_buttons();

  setup_patterns();

  // quick restore defaults.
  if(!digitalRead(BUTTON_1)) {
    RestoreDefault(0);
  } else if(!digitalRead(BUTTON_2)) {
    RestoreDefault(1);
  } else if(!digitalRead(BUTTON_3)) {
    RestoreDefault(2);
  } else if(!digitalRead(BUTTON_4)) {
    RestoreDefault(3);
  }

  build_temp_pattern();

  // reset all the servo positions.
  setup_servos();

  if(i2c_enabled)
    setup_i2c_secondary();

  delay(2000);
  
  if(DEBUG)
    weblog.println(F("Setup Completed."));


}

void loop() {
  if(rebooting) {
    delay(100);
    ESP.restart();
  }

  readSerialCommands();
  readI2CCommands();

  // armTrigger is set by an interrupt - the ISR itself keeps firing regardless of
  // sensor_enabled (it's too trivial to be worth detaching/reattaching for this),
  // this is just where the response to it is gated. Still clears armTrigger on the
  // disabled path, not just when acting on it - operateArm() does that internally,
  // but skipping it entirely would leave a stale true sitting there, ready to fire
  // a phantom move the instant the sensor is re-enabled even though it hasn't
  // actually passed since.
  // Only acted on from the main page (menu_page 0) - on every other page the arms
  // are being programmed, calibrated or left alone, and a carriage pass would
  // otherwise switch them underneath you.
  if(armTrigger) {
    if(sensor_enabled && menu_page == 0) {
      operateArm();
    } else {
      armTrigger = false;
    }
  }

  run_web_actions(); // anything the web UI asked for since the last pass - see webactions.ino
  captive_portal_loop(); // hotspot mode: point every DNS lookup at us - see wifi.ino

  if(pagesFixPending) {
    pagesFixPending = false;
    update_default_pages();
  }

  if(servoTestPending && runEvery(1000, &run400)) {
    testCycleArm(servoTestArm, test_run);
  }

  read_encoder();

    // Update our buttons.
  for (int x = 0; x < 4; x++) {
    debouncer[x].update();
  }
  pgrmDebouncer.update();

    // run our button combo section
  checkButtons();

  detachServo();

  build_temp_pattern();

  // Don't need to update this quite so often.
  if(millis() - displayUpdate >= displayUpdateTimer) {
    display_page();
    displayUpdate = millis();
  }

  check_tone();

  // if it's changed, update the count for each servo.
  if(millis() - countSaveMillis >= countSaveTime) {
    countSaveMillis = millis();
    boolean updateCount = false;
    for(int i = 0; i<4; i++) {
      if(servoCount[i] != oldservoCount[i]) {
        oldservoCount[i] = servoCount[i];
        updateCount = true;
      }
    }
    if(updateCount)
      save_servos(LittleFS, "/servos.txt");
  }

  if (runEvery(1000, &run1000)) {
    // for the first 30 seconds, check if can get on wifi
    if (wifi_enabled && !wifi_connected) {
      if (millis() - wifi_counter <= 30000) {
        setup_wifi();
      } else {
        // We've tried to hit the pre-configured wifi for 30 seconds.
        // time to give up and be our own host (after a quick scan - see wifi.ino).
        start_hotspot();
      }
    }
  }

  // check if we need to do ota activities.
  if(wifi_enabled && wifi_connected) {
    ota_loop();
  }
}

boolean runEvery(unsigned long interval, unsigned long *previousMillis)
{
  unsigned long currentMillis = millis();
  if (currentMillis - *previousMillis >= interval) {
    *previousMillis = currentMillis;
    return true;
  }
  return false;
}

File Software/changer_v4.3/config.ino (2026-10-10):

void setup_config() {
  // load the config from the config.ini file on the LittleFS file system.
  // if the file doesn't exist, load defaults.
  // There's no reason not to add your own options.

  weblog.println(F("Loading Defaults"));

  // Set all our defaults.
  // if we have a config file these will immediately be overridden.
  // but does that matter?  not really.
  
  ssid = PROJECT;
  wifi_password = "";

  http_username = "admin";
  http_password = "admin";

  allowedExtensionsForEdit = "txt, h, htm, html, css, cpp, js, ini, svg";

  jquery = "/jquery-3.6.3.min.js";

  test_run = 10;

  wifi_enabled = true;
  i2c_enabled = false;
  i2c2_address = I2C2_ADDRESS_DEFAULT;
  sensor_enabled = true;
  BUZZER = true;
  buzzerNote = 1046.502;
  DEBUG = 1;

}

void load_config(fs::FS &fs, const char * path) {
  weblog.print(F("Loading Config: "));
  weblog.print(path);

  File file = fs.open(path);
  if(!file || file.isDirectory()){
      weblog.println(F("- failed to open file for reading"));
      weblog.println(F("Creating Default Configuration."));
      save_config(LittleFS, path);
      save_html(LittleFS, "/index.html", index_html);
      save_html(LittleFS, "/autochanger.svg", autochanger_svg);
      save_html(LittleFS, "/manage.html", manager_html);
      save_html(LittleFS, "/ok.html", ok_html);
      save_html(LittleFS, "/edit.html", edit_html);
      save_html(LittleFS, "/failed.html", failed_html);
      save_html(LittleFS, "/join.html", wifi_join_html);
      save_html(LittleFS, "/joining.html", wifi_joining_html);
      return;
  } else {
    weblog.println(F(" - Success!"));
  }

  byte counter1 = 0;

  String temp_name; // lazy and using strings
  String temp_value;
  
  while(file.available()){

      byte temp = file.read();

      if(temp == '=' && counter1 == 0) {
        counter1++;
      } else if(temp == '\n') {
        // run an interpretation.
        if(temp_name != "")
          assign_config(temp_name, temp_value);
        temp_name = ""; // reset our variables.
        temp_value = "";
        counter1 = 0;
      } else if (temp == '\r') {
        // skip carriage return
      } else if(counter1 == 0) {
        // append to the service name.
        temp_name += char(temp);
      } else {
        // everything after the first '=' is the value, including any further '=' (e.g. base64 padding).
        temp_value += char(temp);
      }
  }

  // if there isn't a \n at the end of the file
  // the last config option is skipped.
  if(temp_name != "")
    assign_config(temp_name, temp_value);

  file.close();

  weblog.println(F("Config Load Complete."));

  if(save) {
    weblog.println(F("Updating Wifi Password."));
    save_config(LittleFS, path);
    save = false;
  }
}

void assign_config(String name, String value) {
  // Just a pity we can't automatically do this.

  weblog.print(F("Updating "));
  weblog.println(name);

  if(name == "ssid") {
    ssid = value;
  } else if (name == "wifi_password") {
    wifi_password = decryptXorBase64(value);
  } else if (name == "http_username") {
    http_username = value;
  }else if (name == "http_password") {
    http_password = value;
  }else if (name == "allowedExtensionsForEdit") {
    allowedExtensionsForEdit = value;
  }else if (name == "jquery") {
    jquery = value;
  }else if(name == "test_run") {
    test_run = value.toInt();
  } else if(name == "wifi_enabled") {
    wifi_enabled = value.toInt();
  } else if(name == "i2c_enabled") {
    i2c_enabled = value.toInt();
  } else if(name == "i2c2_address") {
    // 0x00-0x07 and 0x78-0x7F are reserved in the 7-bit I2C address space - ignore
    // anything in those ranges (or unparseable) and keep whatever was already set
    // rather than letting a bad config.ini value take the bus down silently.
    int parsed = value.toInt();
    if(parsed >= 0x08 && parsed <= 0x77)
      i2c2_address = parsed;
  } else if(name == "debounceDelay") {
    debounceDelay = value.toInt();
  } else if(name == "debug") {
    DEBUG = constrain(value.toInt(), 0, 10);
  } else if(name == "sensor_enabled") {
    sensor_enabled = value.toInt();
  } else if(name == "buzzer_enabled") {
    BUZZER = value.toInt();
  } else if(name == "buzzer_note") {
    buzzerNote = value.toDouble();
  }
}
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

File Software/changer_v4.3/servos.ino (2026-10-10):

/*
 * This file contains all the functions relevant to servo operations
 */

 void setup_servos() {
  if(DEBUG)
    weblog.println(F("Configuring Servo."));
    
  pwm.begin();
  
  pwm.setPWMFreq(60);  // Analog servos run at ~60 Hz updates

  load_servos(LittleFS, "/servos.txt");

  if(servosDefaulted) {
    // /servos.txt wasn't found - arms are already out at the eject position (see default_servos()).
    // Open straight into the arm-adjust page on EJECT so it can be checked/tuned right away.
    menu_page = 2;
    menu_position = 4;
  } else {
    for (int x = 0; x < maxServo; x++) {
      if(patterns[currentPattern].length && (patterns[currentPattern].steps[0] - '0') == x)
        moveServo(x,1);
      else
        moveServo(x,0);
    }
  }
  
 }

// we don't really need to hold the servos
// this function turns the servo on, moves it, then switches it off.
// x is the servo number.
// y is the position to move to in the "servos" array
// Last PWM value commanded on each channel, or -1 for unknown (at boot). Tracked here
// rather than read back with pwm.getPWM(), which returns the channel's ON count (always
// 0 here), so every call used to look like a move and inflate servoCount[]. Detaching
// doesn't reset it: an unpowered servo stays where it was put.
int lastPwm[4] = {-1, -1, -1, -1};

void moveServo(int x, int y) {
  if(x < 0 || x > 3 || y < 0 || y > 2)
    return; // a bad arm index would write outside every per-arm array

  armUp[x] = (y == 1); // see the comment on armUp[] in arm.h

  if(lastPwm[x] != servos[x][y]) {
  // only count it, and power the servo, if it's actually going somewhere new.
    servoCount[x]++;
    lastPwm[x] = servos[x][y];
    
     pwm.setPWM(x, 0, servos[x][y]);
    if(DEBUG) {
      weblog.print(F("Moving Servo: "));
      weblog.print(x);
      if(y == 0)
        weblog.println(F(" down."));
      else
        weblog.println(F(" up."));
    }

    // Only reset the timeout on an actual move. If we reset it unconditionally, a caller that
    // polls moveServo() every loop (e.g. armAdjustMode(), to keep the arm synced to a field)
    // would keep the servo powered indefinitely even while sitting idle, since detachServo()
    // never gets a 400ms gap with nothing happening to detach into.
    servoTimeout = millis();
  }
}

// Moves an arm directly to an arbitrary PWM value, bypassing servos[][] entirely -
// used to preview a Low/High/Eject value from the web UI's Arm Positions tab before
// it's been saved, so moveServo()'s "look up servos[arm][field]" wouldn't have the
// right value to use yet. Clamped the same as /servo_save (see webserver.ino) and
// for the same reason - this takes a raw typed value, not one that's already been
// validated.
void previewServo(int arm, int value) {
  if(arm < 0 || arm > 3)
    return;
  value = constrain(value, 0, 4095);
  pwm.setPWM(arm, 0, value);
  lastPwm[arm] = value; // so moving back to a stored position afterwards is a real move
  servoCount[arm]++;
  servoTimeout = millis();
  if(DEBUG) {
    weblog.print(F("Previewing Servo: "));
    weblog.print(arm);
    weblog.print(F(" at "));
    weblog.println(value);
  }
}

// after a given time, detach all servos.
void detachServo() {
  
  if(servoTimeout > 0 && millis() - servoTimeout > 400) {
    for (int x = 0; x < maxServo; x++) {
      pwm.setPWM(x, 0, 0);
      if(DEBUG) {
        weblog.print(F("Detach Servo: "));
        weblog.println(x);
      }
    }
    servoTimeout = 0;
  }
  
}

void switchRods() {
  if(!patterns[currentPattern].length)
    return;
  normalize_servonum();

  moveServo(patterns[currentPattern].steps[servonum-1] - '0', 0);

  servonum ++;
  
  if (servonum > patterns[currentPattern].length) {
    if(DEBUG)
      weblog.println(F("Reset to start"));
    servonum = 1;
  }

  moveServo(patterns[currentPattern].steps[servonum-1] - '0', 1);

}

// Mirrors switchRods() exactly, just stepping backward instead of forward - lowers the
// current arm, steps servonum back one (wrapping to the end instead of the start), then
// raises whatever arm is now current. Used by the web UI's Back button (see /back in
// webserver.ino); the normal forward progression is still driven by the arm sensor via
// operateArm(), this only ever runs on an explicit request to step back.
void switchRodsBack() {
  if(!patterns[currentPattern].length)
    return;
  normalize_servonum();

  moveServo(patterns[currentPattern].steps[servonum-1] - '0', 0);

  servonum --;

  if (servonum < 1) {
    if(DEBUG)
      weblog.println(F("Wrapped to end"));
    servonum = patterns[currentPattern].length;
  }

  moveServo(patterns[currentPattern].steps[servonum-1] - '0', 1);

}
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

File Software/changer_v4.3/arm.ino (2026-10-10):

/*
 * operations related to our arm, ie. the shuttle that moves past the sensor.
 */

// Turns automatic response to the arm sensor on or off and saves the setting - used
// by the serial SENSOR_ENABLE command, the OLED's sensor page, and (indirectly)
// nothing else yet. The sensor itself keeps firing either way; see the gating
// comment in changer_v4.3.ino's loop() for what actually changes. Mainly useful
// alongside the AYAB-facing S/R/L commands (commands.ino) - AYAB driving arms
// directly and the automatic sequence both reacting to every carriage pass would
// fight each other.
void setSensorEnabled(boolean enabled) {
  sensor_enabled = enabled;
  save_config(LittleFS, "/config.ini");
}

void operateArm() {
 // Check if we need to update the arm
    // We only need to do this if our pattern is non-zero
    // If the pattern is 0, it's a manual pattern
    // only do this activity if the 
    if(patterns[currentPattern].length && (millis() - lastDebounceTime) > debounceDelay) {
      if(armCounter == 0){
          switchRods();
          armCounter = 1;
          
          // Turn the buzzer on for 1 second
          if(BUZZER)
            tone(BUZZER_PIN, buzzerNote, 1000);
      }
      else {
          armCounter = 0;
      }

      lastDebounceTime = millis();
    }
    armTrigger = false;
}

// Moves the currently selected arm's servo to match whichever LOW/HIGH/EJECT field is in view.
// Call this only when something actually changes (switching field, switching arm, adjusting a
// value) - never on a bare loop tick. detachServo() releases the servo after 400ms idle; polling
// this every tick would make that release look like a change worth reacting to and re-trigger
// indefinitely, fighting the detach forever.
void syncArmServo() {
  if(menu_position <= 1) {
    moveServo(currentPattern, 0); // LOW
  } else if(menu_position <= 3) {
    moveServo(currentPattern, 1); // HIGH
  } else if(menu_position <= 5) {
    moveServo(currentPattern, 2); // EJECT
  }
}

// Starts (or restarts) a non-blocking test sequence - one arm, or all four in
// sequence - for loop() to carry out over the following seconds (see the
// servoTestPending check in changer_v4.3.ino and testCycleArm() below). Used by
// the web UI's /servo_test and /servo_test_all, and the serial TEST command.
// Explicitly resets armTestCount and armTestAll rather than trusting whatever
// they were last left at: armTestCount only gets reset by testCycleArm() itself
// when a count naturally completes, and armTestAll isn't touched by a single-arm
// request at all - so starting a new test before a previous one finished on its
// own would otherwise inherit a stale count, or have a single-arm request
// unexpectedly cascade into testing the rest because an earlier "all" run never
// got the chance to clear that flag.
void startArmTest(int arm, bool all) {
  armTestCount = 0;
  armTestAll = all;
  servoTestArm = arm;
  servoTestPending = true;
}

// Does the actual cycling, taking the arm directly rather than relying on
// currentPattern - that global is reused for which arm the OLED's arm-adjust page
// has selected, but it's ALSO the active knitting pattern's index. Temporarily
// overwriting it to test a specific arm from the web (which runs concurrently with
// whatever the sensor/main loop is doing) could corrupt an in-progress knit if the
// sensor fires at the wrong moment - this sidesteps that risk entirely by never
// touching currentPattern at all.
void testCycleArm(int arm, int count) {
  if(armUp[arm]) {
    moveServo(arm, 0); // down to LOW
  } else {
    moveServo(arm, 1); // up to HIGH
  }

  armTestCount++;

  if(armTestCount >= count ) { // met our testing requirements
    armTestCount = 0;
    
    if(armTestAll && servoTestArm < 3) {
      // if we're testing all the arms and we haven't hit the end.
      servoTestArm++; // break out and set the global for the next cycle.
      servoTestPending = true; // back in the game
    } else {
      armTestAll = false;
      servoTestPending = false; // finished testing
    }
    
  }
}

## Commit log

2019-11-06 I'm sure there's value here.
    [changer.v.1.7.skp, changer.v.2.0.skp]
2019-11-06 Added basic OLED stuff
    [AutoChanger.kicad_pcb]
2023-10-05 Mounting hardware
    [changer.arm-rake.v.2.0.skp, changer.frame.v.2.4.skp, changer.frame.v.2.5.skp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]
2023-10-05 Tinypico compatible controller
    [AutoChanger.kicad_pcb, AutoChanger.sch]
2023-10-05 Updated for Kicad 7.0
    [AutoChanger.kicad_pcb, AutoChanger.kicad_sch]
2025-11-03 Kicking off another round of development
    [AutoChanger.2.2.kicad_pcb, AutoChanger.2.2.kicad_sch, AutoChanger.kicad_sch]
2025-11-03 V3.8 working
    Oh boy, broken code there.
    Version 4 Software isn't complete.
    Version 3 Software should work.
    [changer_encoder.ino, wifi.ino]
2026-07-01 Cleaned up and updated the latest version of the hardware.
    Geometries tightened. Nobody really needs the old versions.
    [changer.arm-rake.v.2.0.skp, changer.frame.v.2.4.skp, changer.frame.v.2.5.skp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]
2026-07-18 Circuit Board updated to version 3.0
    Circuit board no longer uses a TinyPICO. It uses a ESP32-S3-WROOM module instead. It is also 90% SMD parts and can be assembled by JLCPCB
    [AutoChanger.IR-sensor.kicad_pcb, AutoChanger.kicad_pcb, AutoChanger.kicad_sch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]
2026-07-18 Software version 3.9
    Software v3.9 is a minor update to 3.8 and likely the last of the 3.* series.
    It has it's pin assignments moved to the top, to switch through versions.
    Saving patterns and servo configuration is now on the SPIFFS, rather than the EEPROM which makes it a bit easier to work with.
2026-07-25 changes to jlcpcb tags
    Improving jlcpcb manufacturability. Ideally none of the parts are hand placed.
    [AutoChanger.kicad_pcb, AutoChanger.kicad_sch]
2026-07-25 Changes to gear sizes
    at 100% the gear was slightly too small for the spline. at 105% it fits better
    [changer.v.2.5.gear.stl, changer.v.2.5.skp]
2026-07-25 Updated code for board 3.0 series.
    Still no wifi, but improved pattern saving. Should be compatible with the jump to wifi enabled.
2026-07-25 Burn in command to cycle servos
    cycles through the servos to make sure they are healthy and placed correctly.
2026-07-25 New Servo Setup
    Rethinking servo placement, this tool allows setting and testing of arbitrary servo positions to calibrate each one.
2026-07-25 Cleaning up old versions
    These versions are no longer in development and shouldn't be used.
    [changer_encoder.ino]
2026-07-25 Updated ServoSet
    Now it sets the High and low positions and can trigger a burn-in cycle.
    Eventually this is functionality the main sketch should do.
2026-08-31 Updates to the (last) revision of the version 3 firmware.
    ServoSet lets you set the upper and lower bounds for the servo arms.
    [changer.v.2.5.gear.stl, changer.v.2.5.skp]
2026-09-24 Software Version 4.1
    Version 4.1 includes the best of the 3.9 branch and the 4.1 branch.
    - Basic web server is now included, although it's missing Autochanger specific pages.
    - A long hold on the program button moves through the various menus.
    - "Program" mode now has a "SAV" option to ensure your changes are ready to go.
    - There is an adjust menu for the arm positions.
    - There is a WIFI enable/disable page. Using the interface to join a network is likely not going to be a worthwhile activity.
    - The arms now have an "Eject" mode. This relies on the gear being in the correct position. It's very tight and not all servos are equal.
    [arm.ino, buzzer.ino, changer_encoder.ino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]
2026-09-24 Removing old firmware
    Firmwares v3 and v4.0 should not be used.
    ServoSet is required to adjust the arm positions for version 3.9. It is not needed for version 4.1 onwards.
2026-09-24 Version 3 Hardware
    Changes to the hardware design to make the servos more rigid.
    The frame now has tabs to hold the arms in place.
    Servos now fit in from the top.
    [changer.v.2.5.frame.stl, changer.v.2.5.skp, changer.v.3.0.arm.dxf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]
2026-09-24 Circuit board Version 3.1
    Improvements made to allow manufacturing with PnP machines.
    Geometry is largely unchanged.
    i2c for connections to other systems now has level shifting.
    the sensor and the i2c connector are now using PST 2.0 plugs rather than dupont.
    [AutoChanger.kicad_pcb, AutoChanger.kicad_sch]
2026-09-25 Missing a button hole!
    That could have been embarrassing.
    [changer.v.3.0.skp, changer.v.3.0.top.dxf]
2026-09-28 Updated STL files
    And fixed the nut being 10x too big.
    [changer.v.3.0.frame.stl, changer.v.3.0.nut.stl, changer.v.3.0.skp]
2026-10-04 Added legacy pin numbers
2026-10-05 I2c slave and web updates
    The Autochanger now has an i2c slave connection to communicate with other devices. It mirrors the commands that can be executed on the serial connection and is ready for expansion to directly control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
    The web interface control page has gotten quite a few improvements.
2026-10-06 Final release of version 4.2
    Really pushing what can be considered a point release here.
    The Web interface has received a huge amount of changes. It's now much more custom for the device and includes probably way too much crap, like serial logging.
    [arm.ino, button.ino, changer_encoder.ino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]
2026-10-07 First pass at documentation.
    missing a few images.
    [arm.ino, button.ino, changer_v4.2.ino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]
2026-10-10 Software version 4.3
    This a big one and ticked off a few major problem children.
    Moved from SPIFFS to LITTLEFS. And did it with a file migration built in.
    Updated to the new ESPAsync library.
    Revised the wifi so if you connect on a phone it will open a "join a network" page.
    Cleaned up a bunch of race conditions.
    Added a backup and restore feature.
    Made a bunch of stuff thread safe.
    [Backup.ino, Pages.ino, Webactions.ino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]
2026-10-12 Version 4.3.3
    Apparently I can't stop messing with this. Improvements to sensor code.
2026-10-28 Software version 4.4
    Version 4.4 includes a built in firmware check and upgrade process without the need for extra software.
    It also includes an api endpoint replicating the command structure so other devices (such as AYAB or eKnitter) can communicate to the autochanger wirelessly.
